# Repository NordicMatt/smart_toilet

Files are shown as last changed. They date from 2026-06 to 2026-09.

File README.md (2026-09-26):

# Smart Toilet — voice-triggered flush

> ✨ **Say "Abracadabra," and the toilet flushes.** No buttons, no app —
> just your voice and a little magic.

## The story

This started when the electronic capacitive-sensing toilets I have stopped working
correctly, and I felt the need to fix it. I rigged them up to flush from a button
press, monitored by an Arduino, and added a Hall effect sensor to read the motor
shaft position so it always stops at home.

I'd wanted to make it voice-activated for *years*. I tried with an nRF5340 and Edge
Impulse and could never get it working, so I put it away and lived with the button.

Then Nordic released the new **Edge AI Lab** and **Edge AI add-on**, and everything
changed. I built this ML model in about an hour. You can too — it's genuinely that
easy. And with the **Nordic MCP**, you can do nearly all of it without writing much
code. Give it a try!

I designed the enclosure using **Claude** and **Codex** together, iterating a few
times until everything was the way I liked it. It's the 3D-printed "magic chest" the
hardware lives in below.

Everything here is open source. The one exception is Nordic's AI, which is licensed
to run only on Nordic microcontrollers.

---

**Smart Toilet** is a voice-activated flush actuator for the **nRF54LM20 DK**, built
on the nRF Edge AI add-on. Saying the magic word **"Abracadabra"** drives a flush
motor through one rotation and stops it at the home position using a Hall sensor.

Wake-word detection runs fully on-device on the Axon AI accelerator — **no audio
ever leaves the board.** With the **nRF7002 EB II** Wi-Fi shield the device also
connects to **Memfault** over HTTPS for crash/metric monitoring, reports its flush
count as a Memfault metric, and receives firmware updates over the air via
**Memfault Release Management**. The application runs in **wake-word-only mode**.

- Board target: `nrf54lm20dk/nrf54lm20b/cpuapp` (secure, no TF-M)
- Wi-Fi shield: `nrf7002eb2` (on the P17 expansion connector)
- Application mode: `APP_MODE_WW_ONLY`
- Wake word: "Abracadabra" (`APP_WW_MODEL_ABRACADABRA`)

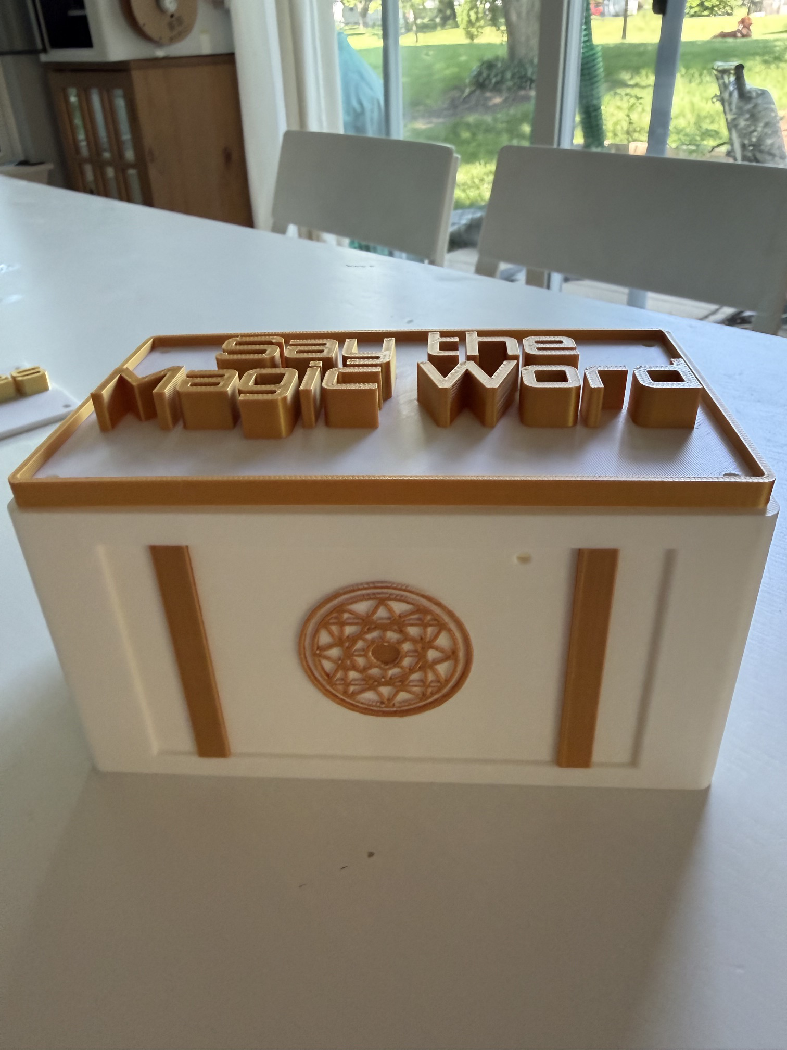
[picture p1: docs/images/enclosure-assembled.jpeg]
Assembled enclosure


The hardware lives in a 3D-printed "magic chest" enclosure (sources in
[`enclosure/`](enclosure/)) whose lid reads *Say the Magic Word*.

| Lid | Internals |
|-----|---|
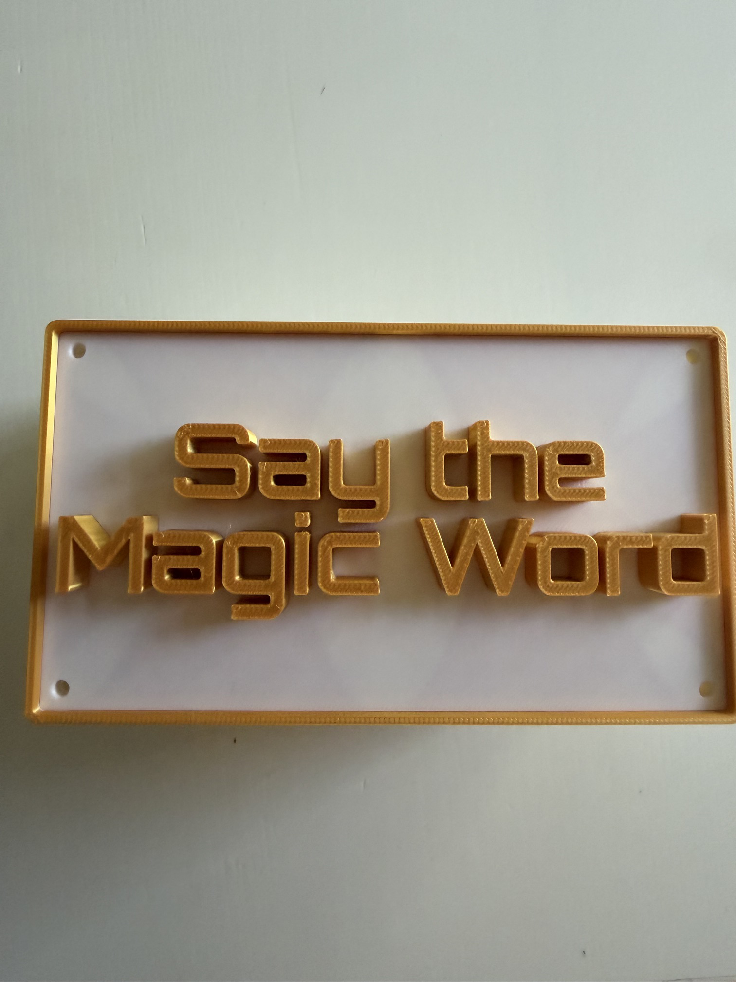
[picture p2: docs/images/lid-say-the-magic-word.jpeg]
Lid lettering
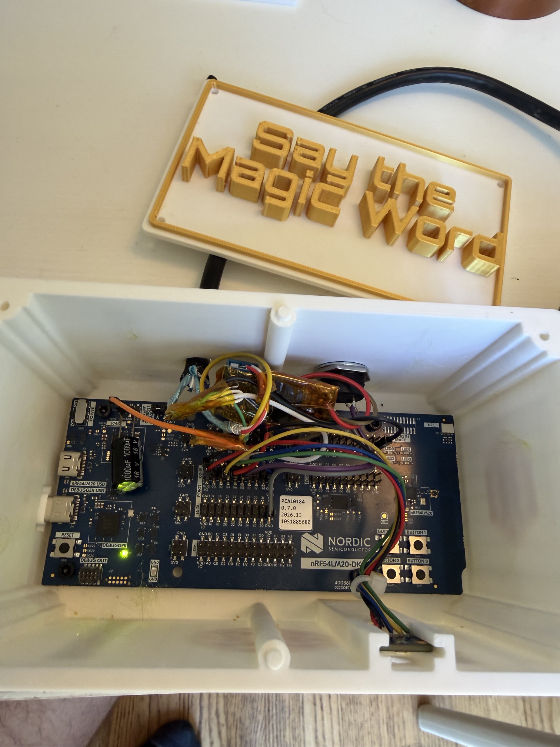
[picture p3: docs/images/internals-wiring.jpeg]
DK wired into the enclosure
|  |  |

## How it works

1. The PDM microphone (`pdm20`) captures single-channel 16 kHz audio (`src/dmic.c`).
2. Each audio block passes through the front-end cleanup chain (`src/audio_proc.c`):
   a fixed PDM hardware gain, a high-pass filter, then software AGC — see
   [Audio front-end](#audio-front-end) below.
3. The wake-word model (an nRF Edge AI Lab model, selected by the
   `APP_WW_MODEL` Kconfig choice) runs on the Axon accelerator (`src/ww/`). A
   detection requires the per-frame probability to exceed
   `CONFIG_WW_PROBABILITY_THRESHOLD` (0.60) for 7 of the last 20 ~30 ms frames,
   plus a ~1 s refractory period so one utterance fires exactly once.
4. On detection, `actuator_flush()` runs the motor and stops it when the Hall
   sensor sees the shaft magnet return home (`src/actuator.c`). LED0 blinks for
   one second and `Wakeword detected` is printed on the control UART (VCOM0).
5. In parallel, `src/cloud.c` brings up Wi-Fi and connects to **Memfault over
   HTTPS** to upload diagnostics, publish the flush count, and check for firmware
   updates. Audio capture only starts **after** the network is up, so the TLS
   bring-up never competes with the wake-word inference for CPU and DMIC buffers.

**Why "Abracadabra":** wake words with more syllables and plosive consonants
survive far-field room reverb far better. The original 2-syllable "Shazaam"
managed only ~50% detection at the deployment distance; "Abracadabra"
(5 syllables, plosive-rich with alternating open vowels) reaches ~95–100%.

## Audio front-end

Each 10 ms audio block is cleaned up before it reaches the model. The chain is,
in order:

1. **PDM hardware gain** — `CONFIG_APP_PDM_GAIN_DB` (default **+20 dB**) applied
   in the PDM peripheral via `nrf_pdm_gain_set()` in `src/dmic.c` (the Zephyr
   DMIC API does not expose gain). Sized for far-field use; without it, speech at
   the deployment distance peaks around −25 dBFS.
2. **High-pass filter** — `CONFIG_APP_AUDIO_HPF`, a 2nd-order Butterworth
   high-pass at **120 Hz**. There is little speech energy below the cutoff, so it
   strips low-frequency rumble and handling noise at negligible cost to the model
   input.
3. **Automatic gain control (AGC)** — `CONFIG_APP_AGC` tracks the speech peak
   envelope and applies a smoothed software gain (±12 dB) that pulls speech
   toward `CONFIG_APP_AGC_TARGET_DBFS` (**−20 dBFS**), so detection is far less
   sensitive to how far the speaker is from the mic.

The AGC acts *after* the PDM hardware gain, so it cannot undo saturation that
already happened in the peripheral — keep `APP_PDM_GAIN_DB` low enough that close
or loud speech does not clip (the model returns ~0 probability on saturated
audio). See [Tuning the mic and wake word](#tuning-the-mic-and-wake-word).

## Hardware / pinout

The EB II mounts on the **P17** expansion connector and claims several pins, so the
toilet peripherals live on header **P2** (GPIO port P1):

| Signal | Pin | Notes |
|---|---|---|
| Motor drive | P1.06 | Active-high → logic-level MOSFET gate |
| Hall sensor | P1.12 | Active-low, internal pull-up; **power the sensor from 5 V** (DK headers P6–P10/P18 pin 1) |
| PDM mic CLK | P1.14 | Adafruit 3492 (ST MP34DT01-M) |
| PDM mic DAT | P1.15 | mic SEL→GND (left channel), VDD→IO rail |
| Wi-Fi | P17 | nRF7002 EB II — don't wire anything else here |

> **Keep all peripheral wires off the `P1` connector block** — that block carries
> GPIO port P0, including the console UART (`P0.06`/`P0.07`). A stray wire there
> makes the console go silent for any firmware.
>
> **Do not use P2.00–P2.05** as header GPIO: the board controller mux routes them
> to the onboard QSPI flash, so the header pins are dead by default.

### Wiring

```
 nRF54LM20 DK                         External circuit
 ------------                         ----------------
 P1.06  ───────────────► gate         logic-level MOSFET
 GND    ───────────────► source       drain ─► motor(-) , motor(+) ─► motor supply +
                                       (flyback diode across the motor)

 5V0 (P6..P18 pin 1) ──► Hall VCC      Hall switch, magnet on the motor shaft
 GND ─────────────────► Hall GND
 P1.12 ◄──────────────── Hall OUT      idles ~3.6 V, pulls to 0 V when magnet present

 P1.14 ──► mic CLK   P1.15 ◄── mic DAT   Adafruit 3492 (SEL→GND, VDD→IO rail)

 P17 expansion connector ◄───────────► nRF7002 EB II (Wi-Fi)
```

Keep all grounds common (DK GND, motor-supply GND, Hall GND). The Hall idles at
~3.6 V, which is at the nRF GPIO input maximum — add a resistor divider if you
see flaky reads.

### Actuator tuning

In `src/actuator.c`:

- `HALL_BLANKING_MS` (250) ignores the Hall sensor right after start — the magnet
  rests on the sensor at home, so without blanking, start-up jitter would end the
  flush immediately.
- `MOTOR_SAFETY_MS` (1000) forces the motor off if the magnet is never sensed
  (jam, misaligned magnet, faulty sensor) so it cannot burn out. One rotation is
  ≈ 700 ms.

## Wi-Fi

Connectivity comes from the **nRF7002 EB II** on P17. `src/cloud.c` uses `conn_mgr`
to bring the interface up and connect, then obtains time over NTP (needed for TLS
certificate validity checks) before connecting to Memfault. The app connects with
Wi-Fi credentials stored in NVS (Zephyr
`wifi_credentials`); provision them with the `wifi cred add -s "<SSID>" -k <keymgmt>
-p "<PASSWORD>"` shell command (on a build with `CONFIG_SHELL`) or compiled-in
static `CONFIG_WIFI_CREDENTIALS_STATIC_SSID`/`_PASSWORD`. Credentials persist across
reboots and a `west flash` without `--erase`.

## Memfault (diagnostics + FOTA)

The device talks only to **Memfault**, directly over **HTTPS** — there is no
nRF Cloud connection. `CONFIG_MEMFAULT_HTTP_ENABLE=y` authenticates with the
Memfault project key (passed at build time — see [Build & flash](#build--flash));
the device serial is the hardware ID. Memfault's TLS root certificates are
provisioned at boot (`CONFIG_MEMFAULT_NCS_PROVISION_CERTIFICATES`), so there are
no application-managed certificates.

What `src/cloud.c` does:

- **Diagnostics** — `CONFIG_MEMFAULT=y` captures coredumps (RAM-backed, surviving
  the warm reset that `CONFIG_RESET_ON_FATAL_ERROR=y` performs after a fault),
  reboot reasons, and metrics, plus a GNU build ID for symbolication. The cloud
  thread drains the Memfault packetizer and POSTs chunks to Memfault over HTTPS.
- **Flush count** — the lifetime count is persisted in NVS (`toilet/flush_count`)
  and published as the Memfault metric **`flush_count`** in each heartbeat, so it
  survives reboots and shows up in the device timeline. (There is no nRF Cloud
  shadow channel, so the old remote-flush command was dropped.)
- **FOTA** — firmware updates are delivered by **Memfault Release Management**.
  `memfault_zephyr_fota_start()` checks the device's cohort for a newer release
  and downloads the signed image over HTTPS into the external-flash MCUboot
  secondary slot; MCUboot swaps it on reboot and the app confirms it once it is
  back online (so it survives a power-cycle). See
  [docs/fota-test.md](docs/fota-test.md) for the full push-an-update flow.

One-time cloud setup: upload the ELF (`build/app/zephyr/zephyr.elf`) under
**Software → Symbol Files** so coredumps symbolicate (matched by the GNU build ID
logged at boot, `mflt: GNU Build ID: …`).

## Tuning the mic and wake word

With `CONFIG_APP_AUDIO_STATS=y` (on by default in `prj.conf`), the log — on **VCOM0**
with the shield (it disables VCOM1) — prints one line of each per second:

```
audio: peak -4.2 dBFS, rms -21.7 dBFS, clipped 0/16000
ww: peak prob 0.62 (bar 0.60), peak votes 4/7
```

Say the wake word from the normal use position and read the lines for that second:

- **`clipped` > 0 or peak pinned at 0.0 dBFS** → the mic is distorting; lower
  `CONFIG_APP_PDM_GAIN_DB` (0.5 dB hardware steps, range −20..+20).
- **Speech peaks below about −20 dBFS** → too quiet for the model; raise
  `CONFIG_APP_PDM_GAIN_DB`.
- **`peak prob` never crosses the bar** even with healthy levels → lower
  `CONFIG_WW_PROBABILITY_THRESHOLD` (in 1/1000).
- **`peak prob` crosses but `peak votes` stays short of the target** → the hits
  are too spread out; lower `CONFIG_WW_COUNT_THRESHOLD` or raise
  `CONFIG_WW_HISTORY_SIZE`.

Set `CONFIG_APP_AUDIO_STATS=n` for the deployed build. (The `CONFIG_APP_AUDIO_SNAP`
audio-recording feature is currently **non-functional in any build variant** —
its raw-UART backend was removed from `control_output.c` when that file was
rewritten to share VCOM0 with printk logging, and never reimplemented. The
Kconfig option is gated off until it's restored; see `app/Kconfig`.)

## Build & flash

Built against an NCS **v3.4.0** tree with the nRF Edge AI add-on passed as extra
Zephyr modules, the Wi-Fi shield, the cloud config overlay, and three secrets kept
out of the repo entirely (`~/.memfault_project_key`, `~/.wifi_ssid`,
`~/.wifi_password` — none of these are committed; cloud.conf only enables
`CONFIG_WIFI_CREDENTIALS_STATIC`, it never contains the actual SSID/password):

```sh
KEY=$(tr -d '\n' < ~/.memfault_project_key)
SSID=$(tr -d '\n' < ~/.wifi_ssid)
WIFI_PW=$(tr -d '\n' < ~/.wifi_password)
nrfutil sdk-manager toolchain launch --ncs-version v3.4.0 --chdir ~/ncs/v3.4.0 -- \
  west build -p always -b nrf54lm20dk/nrf54lm20b/cpuapp -d build app -- \
    -DSHIELD=nrf7002eb2 \
    -DEXTRA_CONF_FILE=cloud.conf \
    -DZEPHYR_EXTRA_MODULES=<addon>/edge-ai \
    -DCONFIG_MEMFAULT_NCS_PROJECT_KEY=\"$KEY\" \
    -DCONFIG_WIFI_CREDENTIALS_STATIC_SSID=\"$SSID\" \
    -DCONFIG_WIFI_CREDENTIALS_STATIC_PASSWORD=\"$WIFI_PW\"
```

Flash and reset (pass `--dev-id <JLINK_SN>` when more than one DK is attached; add
`--erase` when the partition layout changed, e.g. switching from a TF-M /ns image):

```sh
nrfutil sdk-manager toolchain launch --ncs-version v3.4.0 -- \
  west flash -d build --dev-id <JLINK_SN>
```

Footprint: FLASH ~45 %, RAM ~85 % of the nRF54LM20B.

### Fleet (deployed) build

The images on the toilets are the low-power variant, not the plain recipe above:
same command with `-d build_lp` and `-DEXTRA_CONF_FILE="cloud.conf;lowpower.conf"`
(6 h heartbeat, 12 h DRAIN window). Three things that have to line up, learned the
hard way on 2026-09-26 when building 2.3.8 on a machine that had only ever built 2.2.1:

- **Install the toolchain under the SDK's own version name**:
  `nrfutil sdk-manager toolchain install --ncs-version v3.4.0`, then launch with
  `--ncs-version v3.4.0 --chdir ~/ncs/v3.4.0`. Only names printed by
  `nrfutil sdk-manager toolchain list` work; a missing one fails with "Selected
  toolchain was not found". (v3.4.0 and v3.4.0-rc2 resolve to the same bundle,
  fbf7391cab, so an rc2-only install builds identical binaries, but keep the
  release name so the recipe matches the tree.)
- **The Edge AI add-on checkout must be at v2.3.0** (`git -C <addon>/edge-ai checkout
  v2.3.0`). Firmware 2.3.0+ registers the class-streak observability metric; an
  older add-on makes Kconfig abort on the undefined
  `NRF_EDGEAI_OBSV_METRIC_CLASS_STREAK_DIST` symbols.
- **The OTA payload is `app.signed.bin` inside `build_lp/dfu_application.zip`**
  (`unzip -o build_lp/dfu_application.zip app.signed.bin -d build_lp/`), byte-identical
  to `build_lp/app/zephyr/zephyr.signed.bin`. Check the version string in the binary,
  not the build log: `strings build_lp/app.signed.bin | grep Booting`.

Fleet-build footprint (2.3.8): FLASH 40 %, RAM 97.5 %. There is ~13 KB of RAM left;
see PLAN_low_power.md for why the heartbeat interval is coupled to that number.

### Output

With the EB II shield the application console (logs **and** any shell) is on **VCOM0**
(UART30); VCOM1 is disabled by the shield. Use the lower-numbered `ttyACM`/COM port.
`tools/uart_monitor.py` is a small pyserial reader/monitor. Representative lines:

```
cloud: Network ready; uploading to Memfault over HTTPS
main: Network connected; starting audio capture
Waiting for wakeword
Wakeword detected
cloud: Flush #1 recorded
```

## Notes / lessons learned

- **Keep mic/motor/Hall wires on the `P2` connector block, not `P1`.** The console
  UART (`P0.06`/`P0.07`) is on the `P1` block; a stray wire there makes the console
  go silent for any firmware.
- **P2.00–P2.05 are not usable as header GPIO** — the board controller routes them
  to the onboard QSPI flash; disabling the flash in devicetree does not reconnect
  the header pin.
- **Power the Hall sensor from 5 V.** On the 3 V rail it never asserted. The output
  is **active-low** — verify polarity with a meter.
- The flush stop uses a **blanking window**, not a leave-then-return state machine,
  because the magnet rests on the sensor at home.
- **Pick a long, plosive-rich wake word.** Short fricative-led words lose the
  high-frequency energy room reverb destroys. See the `APP_WW_MODEL` choice.
- **Single, bounded heap:** the app uses newlib (required by Edge AI) while the Wi-Fi
  supplicant force-selects `COMMON_LIBC_MALLOC`; both default to a heap at `_end` and
  collide. `CONFIG_COMMON_LIBC_MALLOC_ARENA_SIZE` is fixed so the common heap is a
  static buffer and newlib's `_sbrk` heap gets the region above `_end`.
- **The onboard J-Link can wedge** (VCOM silent / `west flash` J-Link DLL error /
  `Unknown part number 0x33`). Retry `west flash` 1–3×; replug USB if it stays stuck.
- With two DKs attached, always pass `--dev-id <JLINK_SN>` to `west flash`.

## License

This project is licensed under the Nordic 5-Clause License
(`LicenseRef-Nordic-5-Clause`) — see [LICENSE](LICENSE). It is intended for use
with Nordic Semiconductor integrated circuits.

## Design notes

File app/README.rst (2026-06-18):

.. _smart_toilet_app:

Smart Toilet — voice-triggered flush
####################################

.. contents::
   :local:
   :depth: 2

The **Smart Toilet** application is a voice-activated flush actuator for the nRF54LM20 DK.
It detects the magic word **"Abracadabra"** from a digital microphone stream using |EAILib| and Axon-based inference, and on detection drives a flush motor through one rotation.

All inference runs on-device on the Axon AI accelerator; no audio leaves the board.

Application overview
********************

The application samples single-channel 16 kHz audio from a PDM microphone, cleans it up with a front-end audio chain, and feeds it to an nRF Edge AI wake-word model.
By default it runs in **wake-word-only mode** (``APP_MODE_WW_ONLY``): it listens continuously for the single phrase "Abracadabra" and never switches to a keyword-spotting stage.

When the wake word is detected, the application:

* blinks **LED0** for one second,
* prints ``Wakeword detected`` on the control UART (VCOM0),
* runs the flush motor through one rotation and stops it at the home position using a Hall sensor.

Model output is post-processed with a predictions-history window. The detection parameters are the per-frame probability threshold, the predictions-history length, and the number of predictions above the threshold required within that window. A short refractory period ensures a single utterance fires exactly once.

.. note::

   The application also supports wakeword-gated keyword spotting and keyword-spotting-only modes through the ``APP_MODE`` Kconfig choice, and bundles a keyword-spotting model (Go, Stop, Up, Down, Yes, No, On, Off, Right, Left). These are not used by the deployed Smart Toilet, which is wake-word-only.

Wake word
=========

The active wake word is selected by the ``APP_WW_MODEL`` Kconfig choice:

* ``APP_WW_MODEL_ABRACADABRA`` (default) — "Abracadabra", a 5-syllable, plosive-rich phrase from nRF Edge AI Lab. ~95–100% detection at far-field in live testing.
* ``APP_WW_MODEL_OKAY_NORDIC`` — "Okay Nordic", the add-on's bundled 4-syllable model, kept as a known-good reference (~85–90% far-field).

Longer, plosive-rich words survive far-field room reverb much better. A short fricative-led word loses exactly the high-frequency energy that reverb destroys, so it collapses at distance.

Audio front-end
===============

Each audio block is processed in :file:`src/audio_proc.c` before detection, in this order:

#. **PDM hardware gain** — ``APP_PDM_GAIN_DB`` (default +20 dB) applied in the PDM peripheral, sized for far-field use.
#. **High-pass filter** — ``APP_AUDIO_HPF``, a 2nd-order Butterworth high-pass at 120 Hz that strips rumble and handling noise below the speech band.
#. **Automatic gain control (AGC)** — ``APP_AGC`` tracks the speech peak envelope and applies a smoothed software gain toward ``APP_AGC_TARGET_DBFS`` (-20 dBFS), making detection less sensitive to speaker distance. It is gated below -38 dBFS so it rides utterance peaks instead of amplifying room noise.

The AGC acts after the PDM hardware gain and cannot undo saturation in the peripheral itself, so keep ``APP_PDM_GAIN_DB`` low enough that close or loud speech does not clip.

Replacing the model
===================

You can replace the wake-word model using the `Text to Wake Word Detection <Nordic Edge AI Lab Wake Word Detection_>`_ feature of the `Nordic Edge AI Lab`_ or one of the `ready-to-use models <Nordic Edge AI Lab ready-to-use models_>`_:

#. Add the generated files under a new directory in :file:`src/ww/models/`.
#. Add a matching option to the ``APP_WW_MODEL`` Kconfig choice and point :c:func:`ww_init` at the new model instance.
#. Adjust the ``WW_*`` Kconfig options to tune detection post-processing for your model.

Requirements
************

The application supports the following development kit:

.. table-from-sample-yaml::

It also requires a PDM digital microphone connected to the pins specified in the :file:`boards/nrf54lm20dk_nrf54lm20b_cpuapp.overlay` file, and the flush motor and Hall sensor described under `Pin mapping`_. Audio is expected on the left channel.

Pin mapping
===========

The application was tested with an `Adafruit PDM MEMS Microphone`_ module, powered from the 1.8V ``VDD:IO`` supply.

.. list-table::
   :header-rows: 1

   * - Signal
     - nRF54LM20 DK pin
     - Notes
   * - Motor drive
     - ``P1.06``
     - Active-high, drives a logic-level MOSFET gate
   * - Hall sensor
     - ``P1.07``
     - Active-low with internal pull-up; power the sensor from 5V
   * - Microphone ``CLK``
     - ``P1.04``
     - Adafruit PDM MEMS microphone
   * - Microphone ``DAT``
     - ``P1.05``
     - Microphone ``SEL`` → ``GND`` selects the left channel; ``VDD`` → ``VDD:IO`` (1.8V)

.. note::

   Do not use ``P2.00``–``P2.05`` as header GPIO on this DK: the board controller mux routes them to the onboard QSPI flash, so the header pins are inactive by default. Use ``P1``/``P3`` GPIO instead.

To use other microphones, adapt the PDM configuration parameters in the :file:`src/dmic.c` file.

User interface
**************

LED0:
   Blinks for one second when the wake word is detected (wake-word-only mode).

LED1:
   Blinks for one second on each keyword spotted (keyword-spotting modes only).

Flush motor:
   Runs through one rotation on wake-word detection and stops at the home position via the Hall sensor.

UART30 (VCOM0):
   Prints runtime state messages:

   * ``Waiting for wakeword``
   * ``Wakeword detected``

UART (VCOM1):
   Zephyr log output, including actuator events and, when ``APP_AUDIO_STATS`` is enabled, per-second microphone level, AGC gain, and wake-word probability statistics for tuning.

Configuration
*************

|config|

Configuration options
=====================

|application_kconfig|

.. options-from-kconfig::
   :show-type:

Building and running
********************

.. |application path| replace:: :file:`app`

This application is built against the nRF Edge AI add-on. See the repository
``README.md`` for the full ``west build`` and ``west flash`` command lines.

Testing
=======

|test_application|

#. |connect_kit|
#. |connect_terminal_kit| The application uses both serial ports.
#. Open one terminal for the control output from UART30 (VCOM0) and one for the Zephyr log (VCOM1).
#. Say the magic word "Abracadabra" from the normal use position.
#. Observe **LED0** blink for one second and the flush motor run through one rotation.
#. Observe ``Wakeword detected`` on VCOM0.

Application output
==================

The application shows the following output from UART30 (VCOM0):

.. code-block:: console

   Waiting for wakeword
   Wakeword detected

Dependencies
************

This application uses the following |EAI| library:

* :ref:`nrf_edgeai_lib`

This application uses the following Zephyr libraries:

* `Logging`_
* Audio (DMIC)
* GPIO
* UART Driver

API documentation
*****************

.. doxygengroup:: ww_kws

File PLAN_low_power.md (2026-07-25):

# Low-Power Branch Plan

Goal: take the full-connectivity, full-power smart toilet (main branch, v2.0.18)
and find out how low we can push average current, ending with battery operation
on the nPM1300. Voice function stays always-on; connectivity becomes periodic.

## Architecture: duty-cycled connectivity

Replace the always-connected model with a connection window state machine:

- **OFFLINE** (default state): Wi-Fi interface down, nRF70 powered off. No
  association exists, which entirely sidesteps the Nest-mesh silent-drop
  class of problems (nothing to drop) and the link-flap heap pressure
  (no packets). Memfault data (heartbeats, metrics, any coredumps from
  reboots) buffers on-device.
- **DRAIN** (periodic, e.g. every N hours or M heartbeats): bring the
  interface up, connect, upload all buffered Memfault chunks, run one FOTA
  check, then disconnect and power the radio back down. Window closes on
  completion or on a hard timeout so a bad Wi-Fi day cannot pin the radio on.

Audio (PDM capture + AXON inference + flush actuation) runs continuously in
both states. The toilet always hears; it just phones home on a schedule.

## Work items

### Phase 1: connectivity duty cycle (biggest win, most rework)
1. Connection-window state machine in cloud.c: net_if_down/up + conn_mgr,
   nRF70 power off between windows (confirm the driver's power path when the
   interface is administratively down; check whether iface down alone gates
   the RPU or if we need pm_device on the nrf70 node).
2. Memfault buffering between windows: today chunks drain continuously.
   Size the event/chunk storage for the offline period (RAM first; consider
   flash-backed storage if windows get long). Lost-heartbeat behavior after
   watchdog reboots already noted on main; offline buffering makes storage
   sizing matter more.
3. Watchdog semantics rework: the cloud stall monitor and upload-success
   proofs assume continuous connectivity. They must arm only inside DRAIN
   windows. The audio watchdog is untouched.
4. Fleet alerting: the Memfault Device Offline alert (id 21563) fires at
   15 min silent. Raise its threshold above the duty-cycle period (or key it
   to greater than 2x the period) or every sleep window emails everyone.
5. FOTA within the window: check runs once per DRAIN. A pending update
   extends the window until the download/swap completes. Deploy-to-device
   latency becomes up to one period; that is the accepted tradeoff.

### Phase 2: local power reductions (from the axon_low_power sample + earlier findings)
6. CONFIG_PM_DEVICE + CONFIG_PM_DEVICE_RUNTIME, carefully: verify no
   interaction with continuous PDM capture; suspend UARTs and unused
   peripherals. One change at a time with measurements.
7. Quiet build variant: SERIAL/CONSOLE/LOG/PRINTK off (sample's approach).
   Memfault remains the only diagnostics path; acceptable because that is
   how the fleet is debugged anyway. Keep a debug overlay that restores UART.
8. Energy-gated inference (VAD): skip NN passes while block energy sits at
   the room noise floor, with a hangover period and ww_reset() on resume
   (model is stateful). The audio_stats energy accumulator already computes
   what the gate needs. This cuts the AXON + CPU duty cycle during the many
   silent hours; the mic keeps capturing.
9. Audit thread priorities/periods for wakeup reduction (logging thread,
   timers) once measurements identify who wakes the CPU.

### Phase 3: measurement rig (before/throughout, not after)
10. Borrow the axon_low_power GPIO trace pattern: pins high during inference
    and during DRAIN windows, correlated on PPK2. Add a Kconfig'd overlay.
11. PPK2 profiling runbook for the whole board (DK + nRF7002 EB): baseline
    current on main vs low-power branch per phase. Record numbers in this
    file as they land.
12. New heartbeat metrics: time-in-DRAIN per heartbeat, buffered-chunk count,
    connect duration, plus the existing wifi_heap watermark.

### Phase 4: battery (nPM1300)
13. nPM1300 EK integration: devicetree + charger config (400 mA, 4.2 V
    termination per PROFILING.md) + nRF Fuel Gauge library, modeled on the
    NCS npm13xx_fuel_gauge sample.
14. Drop in the Lipo900 battery model .inc from the nPM PowerUP profiling
    run (see PROFILING.md; verify the profile finished and export the model).
15. Battery metrics to Memfault: state of charge, voltage, est. runtime.
    Low-battery behavior: extend duty cycle, then graceful shutdown.

## Open questions (decide before Phase 1 code)
- DRAIN period: hourly? every 6 h? Drives Memfault storage sizing, FOTA
  latency, and the offline-alert threshold. Proposal: start at 1 h.
- Coredump upload urgency: after a crash reboot, connect immediately rather
  than waiting out the period? Proposal: yes, one immediate window on boot.
- Remote knob: duty-cycle period as a Memfault-delivered setting or
  build-time constant? Build-time is simpler; no command channel exists.
- Keep WW-only mode as the low-power baseline (KWS stage stays off).

## Non-goals for this branch
- No changes to wake-word model or thresholds.
- Wi-Fi power-save (PS) stays off even in DRAIN windows; radio-off beats PS
  and avoids the whole silent-drop history.
- No hardware changes until Phase 4.

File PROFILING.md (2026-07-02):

# Battery Profiling Runbook — Li-ion, 3.7 V, 900 mAh

Generate a custom battery model for the nPM1300 fuel gauge using the
nPM PowerUP desktop app + nPM Fuel Gauge Board. The resulting `.inc` file
gets dropped into the smart_toilet firmware later for state-of-charge readings.

> Active profile: **`/home/matt/claude/Lipo900`** (capacity 900 mAh, 4.2/3.0 V,
> iChg 400 mA, 25 °C) — running as of 2026-06-26 (`csvReady: false`, no `.inc`
> yet). The old `smart_toilet/Palo/` folder (3000 mAh) is **stale — ignore it.**

## Battery parameters (decided)

| Field | Value | Note |
|---|---|---|
| Name | `Lipo900` | |
| Chemistry | Li-ion | 3.7 V nominal |
| Termination voltage | **4.2 V** | |
| Discharge cutoff | **3.0 V** | |
| Capacity | **900 mAh** | above the 400 mAh wizard minimum |
| Charge current | **400 mA** | ~0.44C (firmware charger matches) |
| Thermistor | **none / ignore** | 2-wire pack |
| Temperature | **25 °C only** | room-temp model; no chamber needed |

## Hardware required

- [ ] nPM1300 EK
- [ ] nPM Fuel Gauge Board (REQUIRED for a custom model — EK alone can't)
- [ ] PALO DY01 battery
- [ ] USB-C power supply, 1.5 A (charges the PMIC)
- [ ] USB-C cable to computer (nPM Controller)
- [ ] A PC that will NOT sleep/hibernate/auto-restart for ~2–3 days (use flight mode)

## Time expectation

Large cell, current-limited profiling. Charge ~7–8 h, discharge ~5–6 h, run
over multiple cycles. Expect **well over 48 h** for the single 25 °C model.
Run it over a long weekend.

## Step 1 — Attach Fuel Gauge Board to EK

1. [ ] Power off nPM Controller — disconnect USB from **J4**.
2. [ ] Plug Fuel Gauge Board's nPM EK header into the **EXT BOARD** socket.
       ⚠️ Align edge connectors **P1→P20** and **P2→P21** carefully.
3. [ ] Reconnect USB to **J4**. Green **LD4** = controller connected.

## Step 2 — Connect battery + power (no NTC)

1. [ ] Connect DY01 to **J1** (correct polarity).
2. [ ] Jumper **NTC (pin 2) ↔ 10 kΩ (pin 3)** on header **P3**.
       ⚠️ Charging will NOT start if this jumper is missing.
3. [ ] Connect USB-C 1.5 A supply to **J3** (USB PMIC) for charging.

(No nRF DK wiring needed for profiling — the Fuel Gauge Board does the discharge.)

## Step 3 — nPM PowerUP

1. [ ] nRF Connect for Desktop → open **nPM PowerUP**.
2. [ ] **Select Device → nPM1300 Evaluation Kit**.
3. [ ] Click **Profile Battery**.

## Step 4 — Enter wizard parameters

Use the table above. Thermistor = ignore/none, single temperature = 25 °C.
Pick an output folder for the model.

## Step 5 — Run

1. [ ] Start profiling. It charges fully, then discharge↔recharge cycles.
2. [ ] Do NOT change config mid-run (aborts). Keep PC awake. Flight mode on.
3. [ ] ⚠️ Heatsink gets HOT — let it cool before handling afterward.
4. [ ] On completion: model saved as both `.json` and `.inc` in your folder.

## After profiling

- The `.inc` file is the battery model for the firmware.
- Next: integrate nPM1300 into smart_toilet (devicetree + Kconfig + nRF Fuel
  Gauge library) and drop in this `.inc`. Modeled on the NCS
  `samples/pmic/native/npm13xx_fuel_gauge` sample.

## Optional: add temperature accuracy later

If the toilet sees temperature swings, profile at 5 °C and 45 °C separately
(needs a temperature chamber) and merge all three in the nPM PowerUP
**Profiles** tab into one multi-temp model.

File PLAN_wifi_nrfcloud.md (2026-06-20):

# Plan: Add nRF7002 EB II Wi-Fi + nRF Cloud (CoAP) to the Smart Toilet

> **⚠️ Superseded — historical planning record (2026-06-16).** The shipped design
> diverged from this plan: the build target is **`cpuapp`** (secure, no TF-M, not
> `/ns`), and the cloud side moved off nRF Cloud entirely to **pure Memfault over
> HTTPS** (diagnostics + FOTA), so the flush-count shadow and remote-flush command
> were replaced by a `flush_count` Memfault metric (no remote flush). The Wi-Fi
> bring-up and pin re-jumpering below still reflect the hardware. For the current
> architecture see [README.md](README.md) and [docs/fota-test.md](docs/fota-test.md).

**Decisions (2026-06-16):** Transport = **CoAP**; build target = **`nrf54lm20dk/nrf54lm20b/cpuapp/ns`** (TF-M);
cloud features = **flush-event device message + flush-count shadow + remote-flush command (polled)**.

Workspace: `/home/matt/ncs/edge_ai_addon` (already has shield `nrf7002eb2`, nRF70 driver,
`nrf_wifi` blobs, `nrf_cloud` CoAP lib, `nrf70-wifi` snippet, `/ns` board target). No manifest change needed.

## Hardware changes (must happen on the bench)
- **EB II mounts on P17** (expansion connector). It electrically claims: SPI P3.03/P3.02/P3.00/P3.01,
  BUCKEN **P1.04**, IRQ **P1.05**, IOVDDEN P1.13 (coex-only: GRANT P1.07, REQ P0.04, STATUS P0.03 — we will NOT use coex).
- **Mic conflict:** PDM CLK/DAT are on **P1.04/P1.05** → claimed by Wi-Fi. **Re-jumper the mic to two free GPIOs**
  (candidates: the freed UART20 pins, or other non-P17 header GPIOs). Update `pdm20_default_alt`. Verify with a meter.
- **Motor P1.06 / Hall P1.07:** keep, but jumper them on a header *other than P17* (the EB covers P17).
  Electrically free as long as coexistence stays disabled.
- **UART:** shield disables UART20 (VCOM1, the log port) and moves console to UART30 (VCOM0, our control-output port).
  Consolidate logging + control output on VCOM0. **Must disable VCOM1 in nRF Connect Board Configurator.**

## Phase 0 — Snapshot / git
- This repo is now git-tracked. Branch `wifi-nrfcloud`. Commit current working state first.

## Phase 1 — De-risk `/ns` + Axon (GATING SPIKE, before any Wi-Fi)
Axon is a hardware accelerator peripheral; under TF-M it must be assigned to the **non-secure** domain
(plus PDM20, GPIO1 for motor/Hall). Risk: TF-M default may not expose AXON/PDM IRQs to NS.
- Build the **existing** WW-only app for `nrf54lm20dk/nrf54lm20b/cpuapp/ns`.
- Resolve peripheral domain assignment (TF-M `tfm_manifest` / `nrf,peripheral` NS config / DT `*_ns` overlay).
- **Verify wake word still detects on `/ns`** before proceeding.
- Fallback if Axon can't go NS cleanly: revert to secure `cpuapp` and store cloud creds in NVS/settings
  (`TLS_CREDENTIALS_BACKEND_*` non-PSA). Update this plan if we fall back.

## Phase 2 — Wi-Fi link up (no cloud yet)
- `CMakeLists.txt`: `set(SHIELD nrf7002eb2)`; add `nrf70-wifi` snippet.
- `sysbuild.conf`: `SB_CONFIG_WIFI_NRF70=y`, `SB_CONFIG_WIFI_NRF70_SYSTEM_MODE=y`, `SB_CONFIG_BOOTLOADER_NONE=y`.
- `prj.conf`: nRF70 driver + WPA supplicant + native net stack + conn_mgr + L2_WIFI_CONNECTIVITY +
  WIFI_CREDENTIALS + settings/NVS + nRF Security/mbedTLS-DTLS + stacks/heaps
  (base on `nrf_cloud_multi_service/overlay_nrf700x_wifi_coap_no_lte.conf`).
- Wi-Fi credentials: static (`WIFI_CREDENTIALS_STATIC_SSID/PASSWORD`) for first bring-up,
  then move to wifi_cred shell / stored creds.
- Milestone: device associates to AP + gets DHCP IP (conn_mgr L4 connected event).

## Phase 3 — nRF Cloud over CoAP
- Kconfig: `NRF_CLOUD_COAP=y`, `NRF_CLOUD_MQTT=n`, `NRF_CLOUD_CLIENT_ID_SRC_*`,
  `COAP_CLIENT_*`, `DATE_TIME_NTP=y` (no modem time source), `NRF_CLOUD_ALERT`.
- Credentials/onboarding (host PC, separate from build):
  `pip install nrf-cloud-utils`; `device_credentials_installer.py --coap ...` then `nrf_cloud_onboard.py`.
  Creds land in TF-M Protected Storage (`/ns`).
- App: after L4-up → `nrf_cloud_coap_init()` → `nrf_cloud_coap_connect()`.

## Phase 4 — Application integration (the toilet logic)
- New `src/cloud.c/.h`: connection state machine on a workqueue/thread; conn_mgr event handlers.
- **Flush event:** from `actuator.c` flush-complete, post an nRF Cloud **device message** (e.g. `{"flush": {...}}`).
- **Flush counter:** increment a persisted counter (NVS), report to **device shadow** via `nrf_cloud_coap_shadow_*`.
- **Remote flush:** periodic `nrf_cloud_coap_shadow_get(delta=true)`; on a `flush:true` desired delta,
  call `actuator_flush()` and clear the delta. (CoAP is client-driven → poll, e.g. every N s.)
- Keep wake-word → flush path intact; cloud is additive and must never block the audio loop.

## Phase 5 — Verify
- Flash, watch VCOM0: Wi-Fi connect, CoAP connect, message on flush, shadow update in nRF Cloud portal,
  remote flush from portal triggers the motor. Confirm wake-word latency unaffected.

## Open items to confirm during implementation
- Exact two GPIOs for the relocated mic (meter-verify, avoid P2.00–P2.05 QSPI mux).
- Whether flash budget on nRF54LM20B fits Wi-Fi+WPA+mbedTLS+nrf_cloud without MCUboot (sample drops MCUboot for Wi-Fi).
- TF-M partition sizing (Protected Storage for creds).

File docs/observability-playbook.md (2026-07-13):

# Observability Playbook — Finding Fleet Problems Quickly

How the smart-toilet fleet (nRF54LM20 + nRF7002, NCS v3.4.0, Memfault via nRF
Cloud) is instrumented, how to triage an incident in minutes, and the lessons
that were paid for in debugging hours. Distilled from the v1.8.6 → v2.0.6
campaign (June–July 2026): five distinct Wi-Fi/crash root causes, one 14-hour
fleet-wide TLS outage, one FOTA crash loop, and a toddler-induced power event —
all diagnosed remotely except the ones that were physically a plug.

---

## 1. The observability stack (what's on the devices and why)

Layered so that every failure mode leaves evidence, and the evidence arrives
*with* the failure:

| Layer | What it captures | Where configured |
|---|---|---|
| **Reboot reasons** | Every reset with cause + raw `RESETREAS` register | Memfault core (free) |
| **Heartbeat metrics** (10 min) | Audio health (`audio_peak_dbfs`, noise floor, clipping), wake-word quality (`ww_prob_max/mean_pct`, `ww_inferences`, `ww_detections`), usage (`flush_count`, `button_press_count`), network (`wifi_disconnect_count`, `wifi_reconnect_count`), jam detection | `config/memfault_metrics_heartbeat_config.def` + `audio_telemetry.c` |
| **Coredumps** | All-thread backtraces (16 KB RAM-backed, 512 B/thread stacks) on every watchdog/fault | `prj.conf` (`MEMFAULT_RAM_BACKED_COREDUMP_SIZE`) |
| **Logs-in-coredumps** (v2.0.6) | Last ~2 KB of device log lines attached to every coredump — the story leading up to the crash | `CONFIG_MEMFAULT_LOGGING_ENABLE` + 2 KB ring |
| **ML observability CDR** (daily) | Wake-word probability histogram for model-drift monitoring | `CONFIG_NRF_EDGEAI_OBSV*` |
| **Watchdog ladder** | Guarantees every hang becomes a *diagnosed reboot*, not a dead unit | see §3 |
| **Server-side alert** | Device Offline email after 15 min of silence | Memfault alert (API-created) |

The design goal: **a device that fails should explain itself**. When a watchdog
fires, the coredump arrives with the reason, the wedged thread's backtrace, all
other threads, the metrics context, and (since v2.0.6) the log lines that
preceded it.

## 2. Triage: failure signatures → root cause in minutes

The first three API calls for any incident: `device_search` (who's alive, what
version), `device_listReboots` (what happened, when), `issues_list` (is it a
known signature). Then match against this table:

| Signature | Meaning | Go look at |
|---|---|---|
| `Software Watchdog at stall_monitor_expiry` + coredump | Cloud/upload stall ≥ 15–20 min (network outage, TLS failure) | `wifi_reconnect_count` burst in timeseries = outage window; logs in coredump for the TLS/DNS errors |
| `Task Watchdog` (audio) + coredump | Audio pipeline wedged ≥ 60 s (mic dead, model erroring) | Coredump logs will contain the repeating `DMIC read error` / inference error |
| `Hardware Watchdog` **during normal running** | Total lockup — kernel/sysclock dead. If recurring: suspect **memory corruption / ABI mismatch** (library built for a different SDK) | Version history: what library/SDK combination changed? |
| `Hardware Watchdog` **once, at an update** | FIXED in v2.0.11 (WDT budget 120 s → 10 min clears the MCUboot swap against external SPI-NOR). On ≥2.0.11, every HW-watchdog reboot is a real lockup. Historical entries ≤2.0.10 at version boundaries were this artifact | If seen on ≥2.0.11: treat as total lockup |
| `Stack Overflow at <fn>` | A thread's stack is too small for a (new) code path | The named function + coredump `SP` tells you *which* thread's stack Kconfig to bump |
| `Unspecified` / API shows `reason=0, mcu_reason_register=null` | **COLD reset — RAM wiped. This is POWER, not firmware.** Warm resets (all software causes) preserve the reboot-reason RAM | The plug. The USB supply. The child. |
| Offline, **no reboot event**, last heartbeats perfectly healthy | Power loss or total network cut. The device cannot report why it's gone | Physically check LED first; if lit, it self-recovers when network returns |
| `ww_inferences=0` while uptime climbs and uploads flow | Audio pipeline dead but loop alive (pre-v2.0.5 blind spot; now watchdogged) | v2.0.5+ turns this into a Task Watchdog with diagnostic coredump |
| `wifi_disconnect_count` stuck at 0 while the link is clearly dead | Silent half-open drop — radio asleep missed the deauth (power-save). Fixed by `CONFIG_NRF_WIFI_LOW_POWER=n` | Should not recur; if it does, PS got re-enabled |
| Whole fleet dark simultaneously, all versions | **Environment changed, not firmware** — server migration, cert/policy change, router. Rolling back versions will find "all broken" | Test the endpoint from a workstation on the same LAN (§4) |

**Zephyr errno decoder ring** (cost us hours): `errno 113` on Zephyr =
`ECONNABORTED` (TLS handshake aborted) — **not** Linux's `EHOSTUNREACH`. A "TLS
handshake error" log line means TCP already worked; routing/DNS theories are
wrong by construction.

## 3. The watchdog ladder (and its two design rules)

Escalating recovery, lightest first — every tier produces evidence:

| Tier | Trigger | Action |
|---|---|---|
| 0 | No upload 2 min while "connected" | Force Wi-Fi re-associate (no reboot) + `wifi_reconnect_count++` |
| 1 | Audio pipeline no progress 60 s | `MEMFAULT_TASK_WATCHDOG()` → coredump + reboot |
| 2 | Cloud thread no progress 15 min / no upload 20 min | `MEMFAULT_SOFTWARE_WATCHDOG()` → coredump + reboot |
| 3 | Wi-Fi down 10 min after having connected | Reason-marked warm reboot |
| 4 | **Hardware WDT** (nRF54 `wdt31` via `task_wdt`), 120 s | Hard reset even if the kernel is dead |

**Rule 1 — feed on work completed, never on loop-iteration-reached.** The v1.8.6
audio watchdog was fed at the top of the loop; a permanently failing
`dmic_read()` spun through its error path petting the watchdog forever — 45 min
deaf with healthy heartbeats. v2.0.5 feeds only after a mic block is read *and*
accepted by the model. Error paths must not feed.

**Rule 2 — software watchdogs all die together.** Every k_timer-based watchdog
depends on the kernel clock; a hard lockup kills them all silently. The
hardware WDT is not optional — it's the only tier that fires when everything
else is dead. It caught every v1.9.x lockup and contained a regression that
would otherwise have required nightly manual power cycles.

## 4. Debugging techniques that cracked the hard ones

- **`app/debug_net.conf` overlay** — DNS/DHCP/socket debug + mbedTLS handshake
  internals. Gotcha: you need all three of `CONFIG_MBEDTLS_DEBUG=y` (Zephyr
  glue), `CONFIG_MBEDTLS_LOG_LEVEL_DBG=y`, **and** `CONFIG_MBEDTLS_DEBUG_LEVEL=3`
  (nrf_security's prompted default of 0 silently wins otherwise). The payoff is
  decisive: it showed the server answering our ClientHello with `close_notify`
  — the whole TLS outage in one log line.
- **Workstation-as-control**: `openssl s_client` from the same LAN, constrained
  to the device's exact TLS parameters (`-tls1_2 -curves prime256v1 -cipher …
  -sigalgs …`, even `-noservername`), separates "server rejects everyone" from
  "server rejects *this device's* ClientHello".
- **The unrelated-host discriminator**: point the device's client at
  `www.google.com`. Google rejecting the ClientHello too (fatal alert 40)
  proved the ClientHello itself was defective — flipping the investigation from
  "who is blocking us" to "what are we sending". Found PSK-only ciphersuites in
  one step.
- **Raw reboot API beats the pretty UI**: `GET .../devices/<serial>/reboots`
  exposes `mcu_reason_register`. `reason=0` + `register=null` = RAM wiped =
  cold/power reset. This is the definitive power-vs-software discriminator.
- **Verify the binary, not the build log**: `strings zephyr.signed.bin | grep
  memfault.com` caught a "successful" build still carrying old endpoint
  hostnames. Build scripts should end with a self-verification block grepping
  `.config` and the binary for the change just made.
- **Upload symbols for *every* image that touches hardware** — including bench
  builds — or coredumps read "Unknown Location".

## 5. Release & deploy workflow

1. Bump `app/VERSION` **and** `CONFIG_MCUBOOT_IMGTOOL_SIGN_VERSION` (they must
   match; Memfault compares reported vs release version to offer OTA).
2. Pristine build with **`CCACHE_DISABLE=1`** (see lesson below), self-verify
   `.config` + binary.
3. `upload-mcu-symbols` (org token) → `upload-ota-payload` → `deploy-release`
   per cohort (**manager** email+token auth).
4. Watch pickup (~5–10 min: 60 s FOTA check → ~780 KB download → MCUboot swap →
   boot → report). Expect one benign HW-watchdog blip at the swap.
5. **Tag + push only when the version is actually on hardware.** Every flashed
   or OTA'd version gets a git tag — the reboot history is only interpretable
   against exact sources.

**Emergency stop for a bad OTA** (from the FOTA crash-loop incident): offering
*any* release to devices whose download path is broken restarts the loop, so —
`GET /deployments` → `DELETE /deployments/{id}` (manager auth; the org token
gets 403; the release-archive PATCH does not do the job). `deploy-release` of
the old version fails with "already active" when Memfault has auto-reverted —
that error is *good news*. When the download path itself is the bug, cohort
deploys must happen **after** each unit is bench-flashed, never before.

## 6. Lessons learned (the expensive ones)

**Platform & build**
- **Matched versions or memory corruption**: running a prebuilt add-on
  (edge-ai 2.2.0, built for NCS 3.4.0) on a different SDK (3.3.1) produced
  random total lockups — no crash pattern, just a dead kernel every few hours.
  If lockups correlate with a library update, check the ABI pairing first.
- **NCS 3.4.0 / mbedTLS 4.x makes crypto opt-in**: nothing you don't
  `PSA_WANT_*` exists. A Wi-Fi-personal build gets no ECDHE unless the app asks
  (`PSA_WANT_ALG_ECDH`, `ECC_SECP_R1_256`, `RSA_PKCS1V15_SIGN`,
  `ECC_KEY_PAIR_GENERATE/EXPORT`) — without them the TLS client offers
  PSK-only ciphersuites and every public server rejects it. Each missing want
  fails exactly one handshake step further: debug iteratively.
- **The same migration resizes stacks**: PSA-dispatched TLS (esp. SHA-384 PRF)
  needs more stack than legacy mbedTLS. Any thread that does TLS needs a
  re-audit — the `downloader` thread's 4352 B (fine on 3.3.1) overflowed
  fleet-wide on the first 3.4.0 OTA. 8 KB now.
- **ccache does not track `__has_include`**: after *adding* a header that an
  existing `#if __has_include(...)` probes for, cached objects keep the old
  branch — even `-p always` pristine builds. `CCACHE_DISABLE=1` or clear the
  cache.
- **Kconfig hygiene in 3.4.0**: warnings are hard errors; promptless/derived
  symbols (`NRF_SECURITY`, `PSA_WANT_KEY_TYPE_ECC_KEY_PAIR_BASIC`) must not be
  assigned in `.conf` files.

**Networking**
- The NCS Memfault port defaults to **deprecated** hosts
  (`chunks-nrf.memfault.com`); the documented current ones are
  `chunks.memfault.com` / `device.memfault.com` — overridden in
  `config/memfault_platform_config.h`.
- `DNS_RESOLVER_MAX_SERVERS=1`: a single static DNS server *evicts* the
  router's DHCP-provided resolver. Prefer the local resolver + TTL cache.
- Wi-Fi power save on a mesh network = silent half-open drops (radio sleeps
  through the deauth; `wifi_disconnect_count` stays 0). `CONFIG_NRF_WIFI_LOW_POWER=n`
  turned drops into *noticed* disconnects that conn_mgr auto-heals.
- All cloud calls must be time-bounded and are: HTTP poll 5 s, TLS connect
  10 s, DNS 30 s, TCP retransmit ~100 s. A 20-min "stall" is therefore
  *repeated fast failures during a real outage* (routers do overnight
  maintenance), not a hung call — the correct response is visibility
  (`wifi_reconnect_count`), not more timeouts.

**Observability itself**
- **Logs are only as good as their signal density**: a 1 Hz stats log wraps a
  2 KB ring in ~20 s, evicting the error lines the coredump exists to carry.
  Audit what's in the ring before shipping log capture ("do we have logs worth
  grabbing?" is the right question).
- **Per-interval event counters beat lifetime totals** for dashboard metrics
  (`heartbeat_add(1)` per event; keep lifetime totals in NVS if the device
  needs them).
- ISR-context events (button GPIO) stage through an atomic + semaphore; only
  thread context may touch Memfault metric APIs.
- Server-side CDR retention is 1/device/day — collect on that cadence, not
  faster.
- **Physical failures masquerade as software**: a wonky USB plug produced
  "Unspecified" resets and offline gaps that consumed hours as firmware
  theories. Cold-reset signature (§2) + "check the plug first" is the rule.
  Fleet postmortem: since v2.0.1, software outages: 0; power-connector
  outages: 3.

## 7. Incident checklist

```
1. date -u                                    # server clocks may skew from local
2. device_search                              # who's alive, what version
3. device_listReboots (both units)            # what + when; match §2 table
4. issues_list                                # known signature? trace_count growing?
5. If reboot has coredump  → trace_get: faulting thread, backtrace, attached logs
6. If no reboot event      → timeseries: last heartbeats healthy?
     abrupt-stop + no Wi-Fi events = power → check the plug/LED before any theory
7. If network-ish          → wifi_reconnect_count / wifi_disconnect_count timeseries;
     openssl from workstation on the same LAN as control
8. Fix → version bump → pristine CCACHE_DISABLE build → verify .config+binary
   → symbols → payload → deploy → watch pickup → tag + push
```

---

*Every version that ever ran on hardware is a git tag (`v1.8.6` … `v2.0.6`).
The full debugging narrative behind each is in the tagged commit messages —
they are the long-form changelog of this document.*

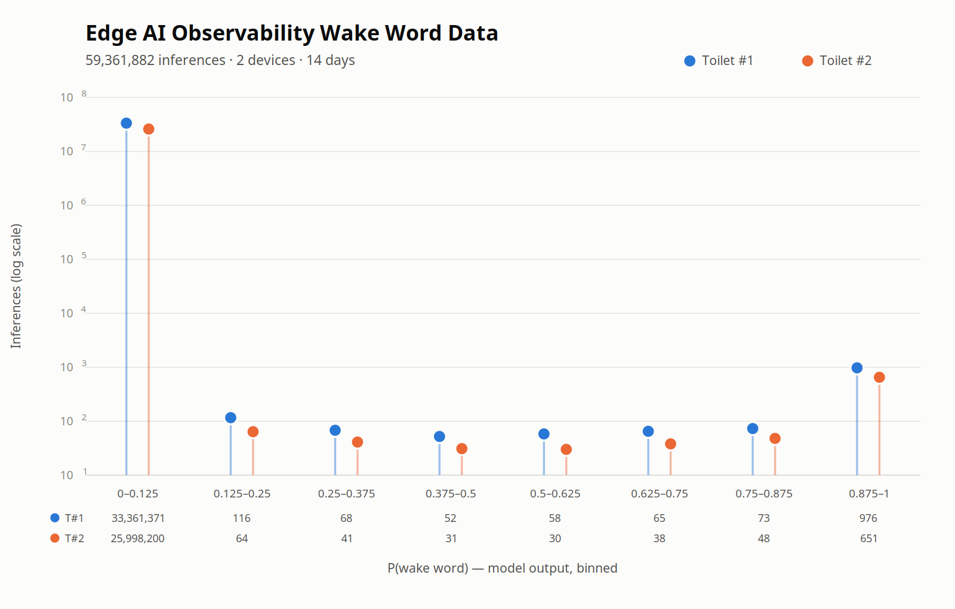
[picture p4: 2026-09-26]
docs/images/ww-confidence-distribution.png

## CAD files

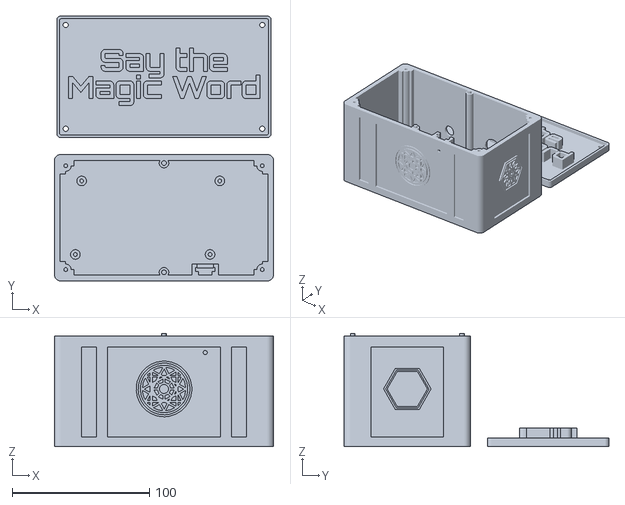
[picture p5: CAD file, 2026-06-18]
enclosure/enclosure.stl
159.6 x 192.8 x 82.5

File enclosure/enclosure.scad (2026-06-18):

/*
  Parametric enclosure for nRF54LM20DK project box.

  Default view renders base and lid separated for printing/inspection.
  Use:
    base();
    lid();
    assembled();
*/

$fn = 64;

use <magic_symbols.scad>   // Symbols traced from the Freepik abstract-symbol pack.

// ---------------------------------------------------------------------------
// Key dimensions
// ---------------------------------------------------------------------------

pcb_length = 145;
pcb_width = 63.5;
pcb_height = 10;

pcb_clearance  = 3;         // Internal clearance at each end (short walls).
side_clearance = 10;        // Internal clearance each long side — extra room for corner boss columns.
standoff_height = 6;        // PCB bottom height above enclosure floor — 6 mm gives M3 thread engagement.
height_above_pcb = 62;      // Free internal height above PCB top for 50.8 mm nRF7002 EB + ~8.5 mm header + margin.

wall_thickness = 2.5;
floor_thickness = 2.5;
lid_thickness = 3.5;        // Thicker top gives room for blind locating-pin pockets.
corner_radius = 3;

standoff_radius = 3.5;
screw_hole_radius = 1.4;    // M3 self-tap pilot (2.8 mm) — enlarged so screws drive in.

lip_depth = 1.5;            // Downward lid lip/rabbet engagement depth.
lip_thickness = 1.5;
fit_clearance = 0.25;       // Small FDM-friendly clearance for lid fit.

// USB-C opening on the left end wall, centered on the actual connector.
// Jack edges observed on the print: top edge at Z = 13.5 (old slot top), left edge
// at Y = -3 (old slot's +Y / left wall). Jack ~9 x 3.2 mm, so its center is offset
// inward by half its size from those edges.
usbc_center_y = -3 - 9/2;   // = -7.5  (left edge -3, minus half the 9 mm width)
usbc_center_z = 13.5 - 3.2/2; // = 11.9  (top edge 13.5, minus half the 3.2 mm height)
usbc_slot_w   = 15;         // Y opening — clears a USB-C cable connector with margin.
usbc_slot_h   = 8.5;        // Z opening.

// Interior front microphone breakout holder.
mic_board_w = 14;           // Mic breakout PCB width (X). VERIFY against actual board.
mic_board_slot_t = 3.0;     // Slot thickness (Y) — roomy fit so the board slides easily and wires have space.
mic_grip = 2.5;             // How much each side rail overlaps the board edge (X, per side).
mic_slot_depth = 18;        // How far down from the tower top the board slides.
mic_relief_t = 2.5;         // Relief pocket depth (Y) between front wall and board center, so the mic housing floats with an air gap.
mic_audio_hole_r = 1.5;     // Front audio hole radius (3 mm diameter).
mic_tower_wall = 2.5;       // Tower wall thickness.
mic_capsule_z_offset = 6;   // Audio hole height above slot bottom; adjust per actual mic capsule layout.
mic_tower_x = 30;           // Clears center locating column, corner bosses, and nearby PCB standoff/front PCB edge.
mic_wire_cut_w = 12;        // Wire exit slot width through the holder's back wall, open at the top so wires drop in.

// Corner bosses and lid screws.
boss_radius     = 4;
boss_hole_r     = 1.4;      // M3 self-tap pilot (2.8 mm) — enlarged so screws drive in.
boss_hole_depth = 12;
lid_screw_r     = 1.9;      // M3 clearance through lid (3.8 mm) — generous so the screw drops through.
gusset_width    = boss_radius * 3;  // Span of rectangular rib along each wall.

// Lid locating posts — chunky columns fused to the inside of the long walls, each
// with a pin on top that drops into a blind hole in the lid. They sit well inboard
// of the edge so the lid has material all the way around each hole (keeps the lid
// bottom flat — the holes are shallow blind pockets, not through-holes).
loc_col_r          = 3.5;   // Locating column radius.
loc_col_inset      = 2.0;   // Column center distance inboard from the inner wall face.
loc_pin_r          = 1.75;  // Pin radius (3.5 mm pin) — printable and sturdy.
loc_pin_h          = 2.0;   // Pin height above the wall rim.
loc_pin_hole_r     = 2.0;   // Lid hole radius = pin radius + clearance.
loc_pin_hole_depth = 2.5;   // Blind depth into the lid (leaves ~1 mm top skin).

label_line_1 = "Say the";
label_line_2 = "Magic Word";
label_font  = "Orbitron:style=Bold";
label_size  = 16;
label_line_pitch = 20;
label_height = 10;          // How far letters stand proud of the top surface.

// Magic-themed lid decorations (raised, like the lettering but lower).
deco_height       = 3;      // How far decorations stand proud of the top surface.
deco_border_inset = 0;      // Border frame flush with the lid edge, clear of the screw heads.
deco_border_width = 2;      // Border frame line width.

// Chest-style trim: bands wrapping the box, corner caps, and vertical straps.
strap_relief  = 1.8;        // How far bands/straps stand proud of the walls.
band_h        = 7;          // Bottom band height (stops just under the USB-C slot).
top_band_h    = 8;          // Top band height, flush with the rim.
strap_w       = 8;          // Vertical strap width.
strap_x       = 45;         // Vertical strap positions on front/back walls (+/-).
corner_cap_w  = 18;         // Corner cap leg length along each wall.

// Wall symbols (traced from the symbol pack, see magic_symbols.scad).
symbol_relief     = 1.2;    // How far symbols stand proud of the walls.
symbol_size_front = 40;     // Front medallion size.
symbol_size_back  = 36;
symbol_size_end   = 34;

// Through-holes in the upper part of the back wall (+Y side).
// (back_hole_z is set below, after base_height is defined.)
back_holes = [                    // Each entry is [x, diameter] along the back wall.
    [  25, 17.5 ],      // Switch mount.
    [ -25, 10.0 ],      // Wire pass-through.
];

part_gap = 14;              // Spacing between base and lid in default view.

// ---------------------------------------------------------------------------
// Derived dimensions
// ---------------------------------------------------------------------------

internal_length = pcb_length + 2 * pcb_clearance;
internal_width  = pcb_width  + 2 * side_clearance;
internal_height = standoff_height + pcb_height + height_above_pcb;

outer_length = internal_length + 2 * wall_thickness;
outer_width = internal_width + 2 * wall_thickness;
base_height = floor_thickness + internal_height;

back_hole_z = floor_thickness + standoff_height + pcb_height + 12;  // Hole centers 12 mm above the PCB top (z = 30.5), near the bottom like the original print.

lid_lip_length = internal_length - 2 * fit_clearance;
lid_lip_width = internal_width - 2 * fit_clearance;
lid_lip_outer_length = lid_lip_length;
lid_lip_outer_width = lid_lip_width;
lid_lip_inner_length = lid_lip_outer_length - 2 * lip_thickness;
lid_lip_inner_width = lid_lip_outer_width - 2 * lip_thickness;

outer_min_x = -outer_length / 2;
front_outer_y = -outer_width / 2;
front_inner_y = -internal_width / 2;

mic_tower_w = mic_board_w + 2 * mic_tower_wall;
mic_tower_depth = mic_relief_t + mic_board_slot_t + mic_tower_wall;
mic_board_channel_w = mic_board_w + 0.5;
mic_relief_w = mic_board_channel_w - 2 * mic_grip;
mic_slot_bottom_z = base_height - mic_slot_depth;
mic_slot_cut_h = mic_slot_depth + 0.4;
mic_slot_cut_z = mic_slot_bottom_z - 0.1 + mic_slot_cut_h / 2;
mic_tower_overlap = 0.05;
mic_slot_wall_bite = 0.1;   // Relief pocket bites slightly into the wall face so the pocket front is exactly the wall.
mic_audio_hole_z = floor_thickness + internal_height - mic_slot_depth + mic_capsule_z_offset;

// ---------------------------------------------------------------------------
// Utility geometry
// ---------------------------------------------------------------------------

module rounded_rect_2d(length, width, radius) {
    offset(r = radius)
        square([length - 2 * radius, width - 2 * radius], center = true);
}

module rounded_box(length, width, height, radius) {
    linear_extrude(height = height)
        rounded_rect_2d(length, width, radius);
}

// PCB hole positions from (0,0) at bottom-left corner of board,
// converted to model coords (centered): subtract pcb_length/2 and pcb_width/2.
pcb_holes = [
    [ 8.0   - pcb_length/2,  5.0   - pcb_width/2 ],
    [ 12.6  - pcb_length/2,  58.5  - pcb_width/2 ],
    [ 106.0 - pcb_length/2,  5.0   - pcb_width/2 ],
    [ 113.1 - pcb_length/2,  58.5  - pcb_width/2 ],
];

module standoff_positions() {
    for (hole = pcb_holes)
        translate([hole[0], hole[1], 0])
            children();
}

module standoff() {
    difference() {
        cylinder(h = standoff_height, r = standoff_radius);
        translate([0, 0, -0.1])
            cylinder(h = standoff_height + 0.2, r = screw_hole_radius);
    }
}

module usbc_slot() {
    // Cut through the left end wall, centered on the USB-C jack.
    // Cube extends slightly past the outer face to avoid coincident-face artifacts.
    translate([
        -(outer_length / 2) + wall_thickness / 2,
        usbc_center_y,
        usbc_center_z
    ])
        cube([wall_thickness + 2 * strap_relief + 0.4, usbc_slot_w, usbc_slot_h], center = true);
}
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

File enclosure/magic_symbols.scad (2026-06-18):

// Symbols traced from abstract-symbol-collection-with-outline (Freepik).
// Each module is a 2D shape normalized to fit a 1 x 1 box, centered.

module symbol_front() {
    polygon(points = [[-0.0208,0.5],[0.0571,0.4974],[0.1455,0.4792],[0.2442,0.4377],[0.3169,0.3883],[0.3896,0.3156],[0.4416,0.2377],[0.4779,0.1519],[0.4987,0.0455],[0.4987,-0.0455],[0.4805,-0.1416],[0.4416,-0.2377],[0.387,-0.3182],[0.3169,-0.3883],[0.2182,-0.4506],[0.1039,-0.4896],[0.0182,-0.5],[-0.0545,-0.4974],[-0.1532,-0.4766],[-0.2468,-0.4351],[-0.3221,-0.3831],[-0.3844,-0.3208],[-0.439,-0.2403],[-0.4779,-0.1468],[-0.4987,-0.0325],[-0.4961,0.061],[-0.4805,0.139],[-0.439,0.2403],[-0.3844,0.3208],[-0.3195,0.3857],[-0.2286,0.4455],[-0.1455,0.4792],[-0.0156,0.4766],[-0.1195,0.461],[-0.2156,0.4247],[-0.2961,0.3727],[-0.3584,0.313],[-0.4156,0.2325],[-0.4519,0.1494],[-0.4727,0.0558],[-0.4753,-0.0273],[-0.4649,-0.1026],[-0.4286,-0.2065],[-0.3714,-0.2974],[-0.3169,-0.3545],[-0.2597,-0.3987],[-0.1818,-0.4403],[-0.0831,-0.4688],[0.013,-0.4766],[0.0987,-0.4662],[0.2104,-0.4273],[0.3065,-0.3649],[0.3662,-0.3052],[0.413,-0.2377],[0.4571,-0.1364],[0.4753,-0.0403],[0.4753,0.0403],[0.4571,0.1364],[0.4208,0.2247],[0.3662,0.3052],[0.3039,0.3675],[0.2312,0.4169],[0.1481,0.4532],[0.0519,0.474],[-0.0208,0.4247],[0.0519,0.4221],[0.1273,0.4065],[0.2104,0.3701],[0.2649,0.3338],[0.3195,0.2818],[0.3714,0.2091],[0.4078,0.1234],[0.4234,0.0455],[0.4234,-0.0455],[0.4078,-0.1234],[0.374,-0.2039],[0.3532,-0.2403],[0.3481,-0.2403],[0.3169,-0.2844],[0.2416,-0.3519],[0.1688,-0.3909],[0.0961,-0.4143],[0.0182,-0.4247],[-0.0494,-0.4221],[-0.1247,-0.4065],[-0.2052,-0.3727],[-0.2701,-0.3286],[-0.3273,-0.2714],[-0.3714,-0.2065],[-0.4052,-0.1286],[-0.4234,-0.0325],[-0.4208,0.0558],[-0.4052,0.1286],[-0.3688,0.2117],[-0.3299,0.2688],[-0.2675,0.3312],[-0.2052,0.3727],[-0.1169,0.4091],[-0.0156,0.4013],[-0.0805,0.3935],[-0.1273,0.3805],[-0.1922,0.3519],[-0.2078,0.3364],[-0.0805,0.2688],[-0.0104,0.3987],[0.0182,0.3987],[0.0857,0.2714],[0.2104,0.339],[0.1558,0.3701],[0.1117,0.3857],[0.0468,0.3987],[0.0052,0.3753],[-0.0597,0.261],[-0.0338,0.2429],[0.0338,0.2429],[0.0649,0.261],[-0.2442,0.3156],[-0.3065,0.2584],[-0.3143,0.2429],[-0.2442,0.2429],[-0.2156,0.3156],[-0.2182,0.2429],[-0.0935,0.2429],[-0.0987,0.2532],[0.2208,0.3156],[0.1013,0.2532],[0.1013,0.2429],[0.2208,0.2429],[0.2468,0.3156],[0.2442,0.2429],[0.3169,0.2429],[0.2909,0.2766],[-0.3143,0.2195],[-0.2545,0.1026],[-0.2442,0.0948],[-0.2442,0.2195],[-0.2182,0.2195],[-0.2182,0.1104],[-0.213,0.1104],[-0.1455,0.1468],[-0.1091,0.2195],[-0.0805,0.2195],[-0.1065,0.1701],[-0.026,0.2117],[-0.0364,0.2195],[0.039,0.2195],[0.0286,0.2091],[0.1143,0.1649],[0.0883,0.2195],[0.1143,0.2195],[0.1532,0.1442],[0.2208,0.1078],[0.2208,0.2195],[0.2442,0.2195],[0.2442,0.0948],[0.2545,0.0922],[0.3221,0.2195],[-0.3377,0.2117],[-0.3688,0.1571],[-0.3844,0.113],[-0.4,0.0117],[-0.2701,0.0792],[0.3403,0.2039],[0.2753,0.0792],[0.4,0.0117],[0.387,0.1078],[0.3688,0.1597],[0.3506,0.1961],[-0.0078,0.1935],[-0.1169,0.1338],[-0.0727,0.0896],[-0.0442,0.1052],[-0.0078,0.113],[0.0156,0.1883],[0.0156,0.1104],[0.0442,0.1052],[0.0753,0.0844],[0.1247,0.1286],[0.1195,0.1364],[-0.1325,0.1182],[-0.1922,0.0091],[-0.1117,0.0091],[-0.1065,0.0403],[-0.0883,0.074],[0.1403,0.113],[0.0935,0.0688],[0.1091,0.0351],[0.1117,0.0117],[0.1974,0.0117],[0.1455,0.113],[-0.1688,0.1078],[-0.2182,0.0818],[-0.2182,0.0351],[-0.213,0.0273],[0.1818,0.1026],[0.1792,0.0974],[0.1922,0.0714],[0.2208,0.0273],[0.2208,0.0818],[-0.0104,0.0896],[-0.0468,0.0766],[-0.0701,0.0558],[-0.0883,0.0169],[-0.0883,-0.0143],[-0.0753,-0.0481],[-0.0571,-0.0688],[-0.0208,-0.087],[0.0078,-0.0896],[0.0519,-0.074],[0.0727,-0.0532],[0.0883,-0.0195],[0.0883,0.0195],[0.0753,0.0506],[0.0519,0.074],[0.0234,0.087],[-0.2623,0.0584],[-0.374,-0.0039],[-0.2597,-0.0636],[-0.2442,-0.0377],[-0.2442,0.0377],[-0.2519,0.0532],[0.2649,0.0584],[0.2442,0.0247],[0.2442,-0.0247],[0.2649,-0.061],[0.374,-0.0039],[0.1117,-0.0117],[0.1065,-0.0429],[0.0883,-0.0714],[0.1403,-0.1208],[0.1974,-0.0117],[-0.1896,-0.0143],[-0.1403,-0.1104],[-0.1273,-0.1234],[-0.0831,-0.0766],[-0.1039,-0.0455],[-0.1117,-0.0143],[-0.3974,-0.0169],[-0.3974,-0.0506],[-0.3844,-0.113],[-0.3688,-0.1571],[-0.3377,-0.2091],[-0.2727,-0.0844],[0.4,-0.0169],[0.2779,-0.0818],[0.3403,-0.2039],[0.3532,-0.1909],[0.3844,-0.1156],[-0.2104,-0.0273],[-0.2182,-0.0351],[-0.2182,-0.087],[-0.1662,-0.113],[0.2208,-0.0273],[0.213,-0.0325],[0.174,-0.1104],[0.2208,-0.087],[0.0727,-0.087],[0.0442,-0.1052],[0.013,-0.1104],[0.013,-0.1961],[0.1221,-0.139],[-0.0623,-0.0922],[-0.1143,-0.1442],[-0.0104,-0.1961],[-0.0104,-0.113],[-0.0442,-0.1052],[0.2519,-0.0948],[0.2442,-0.1],[0.2442,-0.2195],[0.3221,-0.2195],[0.2571,-0.0948],[-0.2468,-0.0974],[-0.2545,-0.1026],[-0.3143,-0.2195],[-0.2442,-0.2195],[-0.1636,-0.113],[-0.1662,-0.113],[-0.1662,-0.1156],[-0.1636,-0.1156],[0.2208,-0.113],[0.1506,-0.1494],[0.1143,-0.2195],[0.2208,-0.2195],[-0.2182,-0.1156],[-0.2182,-0.2195],[-0.1091,-0.2195],[-0.1455,-0.1519],[0.1065,-0.1727],[0.0338,-0.2117],[0.0286,-0.2195],[0.0883,-0.2195],[0.1117,-0.1753],[-0.1013,-0.1753],[-0.1039,-0.1753],[-0.1039,-0.1779],[-0.1013,-0.1779],[-0.1013,-0.1779],[-0.0805,-0.2195],[-0.026,-0.2195],[-0.3143,-0.2429],[-0.3039,-0.261],[-0.2442,-0.3156],[-0.2442,-0.2429],[-0.2182,-0.2429],[-0.2182,-0.3208],[-0.0909,-0.2532],[-0.0935,-0.2429],[-0.0234,-0.2429],[-0.0571,-0.2636],[0.0052,-0.3753],[0.0623,-0.2636],[0.0234,-0.2429],[0.1013,-0.2429],[0.0961,-0.2558],[0.1039,-0.261],[0.2208,-0.3208],[0.2208,-0.2429],[0.2442,-0.2429],[0.2468,-0.3156],[0.2883,-0.2792],[0.3169,-0.2429],[-0.0779,-0.274],[-0.2052,-0.3442],[-0.1195,-0.3831],[-0.0442,-0.3987],[-0.013,-0.3987],[0.0831,-0.2766],[0.0182,-0.3987],[0.0623,-0.3961],[0.1195,-0.3831],[0.2052,-0.3442],[0.1948,-0.3338]], paths = [[0,1,2,3,4,5,6,7,8,9,10,11,12,13,14,15,16,17,18,19,20,21,22,23,24,25,26,27,28,29,30,31],[32,33,34,35,36,37,38,39,40,41,42,43,44,45,46,47,48,49,50,51,52,53,54,55,56,57,58,59,60,61,62,63],[64,65,66,67,68,69,70,71,72,73,74,75,76,77,78,79,80,81,82,83,84,85,86,87,88,89,90,91,92,93,94,95,96,97],[98,99,100,101,102,103,104],[105,106,107,108,109,110],[111,112,113,114,115],[116,117,118,119],[120,121,122,123],[124,125,126,127],[128,129,130,131],[132,133,134,135],[136,137,138,139,140],[141,142,143,144],[145,146,147,148],[149,150,151,152],[153,154,155,156],[157,158,159,160,161],[162,163,164,165,166,167],[168,169,170,171,172],[173,174,175,176,177,178],[179,180,181,182,183],[184,185,186,187,188,189],[190,191,192,193],[194,195,196,197,198],[199,200,201,202,203,204,205,206,207,208,209,210,211,212,213,214],[215,216,217,218,219,220],[221,222,223,224,225],[226,227,228,229,230],[231,232,233,234,235,236],[237,238,239,240,241,242],[243,244,245,246,247],[248,249,250,251],[252,253,254,255],[256,257,258,259,260],[261,262,263,264,265],[266,267,268,269,270],[271,272,273,274],[275,276,277,278],[279,280,281,282],[283,284,285,286],[287,288,289,290,291],[292,293,294,295],[296,297,298],[299,300,301,302],[303,304,305,306],[307,308,309,310,311],[312,313,314,315,316],[317,318,319,320],[321,322,323,324,325],[326,327,328,329,330,331]]);
}
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

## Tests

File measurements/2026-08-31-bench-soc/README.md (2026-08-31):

# 2026-08-31 bench SoC captures — inference cost split

Rig: second nRF54LM20 DK (J-Link **1051814190**) + nRF7002 EB II, PPK2 in
**ampere-meter mode at P14** (VDD:nRF, 1.8 V), no microphone attached, no
motor/Hall. This DK does not enumerate on USB until PPK2 DUT power is on.
Firmware: `low-power` branch bench builds (300 s DRAIN period). Capture:
`tools/ppk2_capture.py --seconds 380 --voltage-mv 1800`, P1.13 marker not
wired (threshold split in post).

| Capture | Build | Floor (windows excluded) |
| --- | --- | --- |
| `soc_run1` | `2.2.1-bench` (full pipeline) | **0.648 mA** |
| `soc_noinfer` | `2.2.1-bench-noinfer` (`-DAPP_BENCH_NO_INFERENCE`: capture + DSP, `ww_process()` skipped, watchdog fed) | **0.285 mA** |

**Inference = 0.363 mA, 56 % of the SoC floor.** That is the measured
ceiling on what an audio-level (VAD) gate could save in a quiet room.
Details and interpretation in `docs/POWER_MEASUREMENT.md`.

Files:

- `soc_*_1ms.csv` — 1 ms downsample (`t_s, mean_uA, max_uA`), plot-friendly.
- `raw/soc_*.csv.gz` — full ~85 kS/s captures (~600 MB uncompressed each,
  `index,current_uA,digital`). Kept out of git; do not commit.

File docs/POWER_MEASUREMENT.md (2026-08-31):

# PPK2 current measurement (low-power branch)

Measured 2026-07-27 on a third nRF54LM20 DK + nRF7002 EB II running
`build_bench` (`app/bench_power.conf`, 300 s DRAIN period). Tool:
`tools/ppk2_capture.py`.

## Results

| Subsystem | State | Current |
| --- | --- | --- |
| **nRF7002** (5 V feed) | radio OFF, between windows | **0.087 mA** |
| **nRF7002** (5 V feed) | radio ON, 34 s window | **43.07 mA** (peak 305.8) |
| **nRF54LM20B** (VDD:nRF @ 1.8 V) | always-on audio + inference | **0.664 mA** |
| **nRF54LM20B** | during a window | ~2.9 mA (peak 20.5) |

**The RPU does power down.** 87 µA on the radio's 5 V feed is regulator
quiescent plus leakage; an nRF7002 left energised sits in the tens of mA.
The ratio between window and sleep is **1:495**. This closes the doubt
`PLAN_low_power.md` step 1 raised, with a measurement instead of an
inference. The `net_if_down ... Error: -120` (`-EALREADY`) logged at window
close is benign.

Projected radio average at the shipped 12 h period:

```
window:  43.07 mA x    34 s =  1464 mA·s
sleep:   0.087 mA x 43200 s =  3758 mA·s
                      total =  5223 mA·s / 43234 s = 0.121 mA
```

Sleep dominates at 12 h, so shortening the window buys almost nothing.
Further gains have to come from lowering the 87 µA floor.

### Budget and what is NOT in it

| Subsystem | Average | Source |
| --- | --- | --- |
| SoC | ~0.68 mA | measured |
| Radio @ 12 h duty | ~0.12 mA | measured |
| **Measured subtotal** | **~0.80 mA** | |
| PDM mic (MP34DT01-M) | ~0.65 mA | datasheet, NOT measured |
| Hall sensor, ungated | ~5 mA | typical part, NOT measured |
| Motor | unknown | NOT measured |

On a 900 mAh cell: SoC + radio ≈ 48 days; add the mic ≈ 26 days; add an
ungated Hall ≈ 6 days.

**`VDD:IO` is a buffered follower of `VDD:nRF`**, deliberately arranged so
shield I/O current is not drawn through the measured rail. The P14 figure is
therefore the **SoC only** — mic, external flash and the nRF7002's IOVDD are
in neither capture.

The 43 mA window figure includes the EB II's 5 V -> 3.6 V regulator, which
the battery design deletes, so the product number will be better.

## Setup as actually used

Both measurements are **ampere meter mode, in series**. The board keeps
supplying itself; the PPK2 only counts electrons. No sourcing, so no
brownout risk from the meter.

### Radio: cut SB31

The EB II's P10/P4 measurement headers are unreachable once the board is
seated, so the radio is measured upstream instead.

`SB31` ("cut to disconnect VBUS from 5V0:CONN") isolates the connector 5 V
rail that feeds the power headers P6-P10/P18, and hence the EB II. Cut it
and bridge the gap with the PPK2 in series: `VIN` to the VBUS side, `VOUT`
to the `5V0:CONN` side.

> **After cutting SB31 the radio only has power while the PPK2 has DUT
> power ON.** Between captures Wi-Fi is dead and every DRAIN window fails to
> connect. That is the rig, not a firmware regression. To run the DK
> normally, bridge the gap with a plain wire.

Non-destructive alternative, if starting over: interrupt **pin 1 only** of
the DK power header the EB II's P2 seats on (bend the pin, or use a riser)
and put the PPK2 in series there. Same measurement, nothing cut. The two
pinouts mate 1:1 — DK header pin 1 is `5V0 from PMIC`, EB II P2 pin 1 is
`VDD_VBAT`.

### SoC: P14, ampere mode

Remove the P14 jumper and connect the PPK2 **between pins 1 and 2**, which
is Nordic's documented ampere-meter setup for this DK. The onboard nPM1300
keeps supplying `VDD:nRF` at its native 1.8 V, so there is no risk of
running the SoC at the wrong voltage.

Source-meter mode at P14 also works (`--source-mode`, 1.7-3.6 V allowed),
but then the PPK2 *is* the supply and the DK must already be powered over
USB before output is enabled, or the onboard circuitry can be damaged.
Ampere mode avoids the ordering hazard entirely.

> With the P14 jumper out and the PPK2 in series, **the SoC only has power
> while DUT power is ON**, so the DK reboots when a capture starts.

## Where NOT to inject

`VBUS` feeds the **nPM1300 PMIC**, which generates every downstream rail.
Driving 5 V into `VBUS` or a `5V0` net while USB is also connected puts two
sources in parallel and current arrives via a path you are not measuring.

There is **no 5 V input that reaches the SoC**: the external supply header
is P14, rated **1.7-3.6 V**. The P6-P10/P18 headers are 5 V *outputs*.

Do not cut `SB18` for this. It separates `VSYS` from `P5V0`, and `VSYS` is
the PMIC's main system rail; it does not isolate the shield supply.

## Running a capture

```
tools/ppk2_capture.py --seconds 380                      # radio, 5 V rail
tools/ppk2_capture.py --seconds 380 --voltage-mv 1800    # SoC at P14
```

Always pass a `/dev/serial/by-id/...` path. **ttyACM numbers get reassigned**
when devices re-enumerate, and the PPK2 and the DK swap places.

380 s covers a full bench cycle (~34 s window + 300 s sleep).

### If the PPK2 returns garbage

Symptoms: `UnicodeDecodeError` reading modifiers, ~7 samples/s instead of
~80 000, absurd currents. The device was left mid-stream by a previous
session. `ppk2_capture.py` now quiesces automatically on connect; by hand it
is opcode `0x07` (AVERAGE_STOP) then drain. **`0x0d` is `REGULATOR_SET`, not
average-stop** — sending it by mistake misconfigures the device. `0x20` is a
full RESET, after which the device re-enumerates and the ttyACM number
changes.

### Other gotchas

- Close the serial terminal before taking real numbers; Nordic warn readings
  are noisy while the virtual serial port is open
- The window marker (`CONFIG_APP_POWER_MARKER`, P1.13) was **not wired** for
  these captures, so the split was done on current threshold. With 495x
  separation that is unambiguous, but wiring P1.13 to a PPK2 digital input
  gives exact edges
- LED1 pulses 20 ms every 5 s (`CONFIG_APP_LED_HEARTBEAT`), so expect a small
  periodic blip rather than a DC offset. A wake-word detection blinks it for
  a full second, so avoid talking near the unit mid-capture
- nRF Connect for Desktop polls serial ports for device discovery, which can
  disturb a scripted capture. Close it first

## SoC optimisation attempts (2026-07-27)

All measured at P14, ampere mode, 1.8 V, same 180-380 s method.

| Build | baseline | vs bench |
| --- | --- | --- |
| bench (serial + log + console) | 0.650 mA | — |
| `bench_quiet.conf` (SERIAL/CONSOLE off) | **0.622 mA** | **-28 uA** |
| `bench_pm.conf` (PM_DEVICE + RUNTIME) | 0.649 mA | ~0 |

**`PM_DEVICE_RUNTIME` saves nothing — do not adopt.** Functionally safe
(audio ran, DHCP landed, window completed, watchdog quiet), but the
peripherals that dominate are the ones actively in use. See
`app/bench_pm.conf`.

**`CONFIG_PM` is unavailable.** It depends on `HAS_PM`, which nRF54LM20 does
not advertise in NCS 3.4.0. Not a loss: the idle path is WFI, which is how
nRF54L reaches System ON IDLE (~3 uA).

**Serial-off was NOT promoted to the field build.** 28 uA is ~4% of the SoC
baseline and ~2% of the system budget, and the console has repeatedly been
needed for debugging. See `app/bench_quiet.conf`.

### DC/DC is already on — and your custom board must replicate it

The DK's board DTSI sets `&vregmain { status = "okay";
regulator-initial-mode = <NRF5X_REG_MODE_DCDC>; }`, confirmed as
`regulator-initial-mode = <0x1>` in the generated devicetree. Omitting this
is what left a DevZone custom board at **98 uA instead of ~1 uA** in System
OFF. It is the single highest-consequence line in a custom board's DTS.

### Where the SoC's power actually goes

Nordic quote System ON IDLE at ~3 uA; we measure ~620 uA. So **~99.5% of the
SoC draw is the work itself** — continuous PDM capture plus inference. No
configuration switch touches that. Reducing it means changing the algorithm
(e.g. a cheap voice-activity first stage gating the expensive model), not
the build config. For scale, the mic alone is ~650 uA per its datasheet,
comparable to the whole SoC, and sits outside this measurement on the
VDD:IO follower.

The two changes actually worth making are elsewhere: **gate the Hall
sensor** (~5 mA continuous) and **feed nRF7002 VBAT directly** (deletes the
EB II regulator and most of the 87 uA radio floor).

## SoC inference split (2026-08-31)

Measured on a second nRF54LM20 DK (J-Link **1051814190**) + EB II, PPK2 at
P14 ampere mode, no mic attached (the PDM peripheral clocks and DMAs
regardless; per-block model compute is data-independent, so the floor is
representative). Raw + downsampled traces in
`measurements/2026-08-31-bench-soc/`. Note: this DK does not enumerate on
USB until PPK2 DUT power is on.

| Build | Floor (windows excluded) |
| --- | --- |
| `2.2.1-bench`, full pipeline | **0.648 mA** |
| `2.2.1-bench-noinfer` (capture + DSP, no `ww_process()`) | **0.285 mA** |

**Inference is 0.363 mA — 56 % of the SoC floor.** This reproduces July's
baseline (0.648 vs 0.650) and finally splits it: the remaining 0.285 mA is
PDM capture + DMA + HPF/AGC/stats + idle. The raw trace is bimodal (median
0.305 mA under the full pipeline): the CPU already idles between per-block
compute bursts.

Consequence: an audio-level (VAD) gate that skips inference during silence
has a measured ceiling of **~0.36 mA** — by far the largest SoC lever, and
it confirms the July hypothesis quantitatively. A real gate keeps: cheap
`block_peak` (already computed by the AGC) with hysteresis + a few-hundred-
ms hangover, a pre-roll ring buffer to prime the model's ~1 s feature
history on gate-open, and a vote/refractory reset in `wakeword.c`. It only
pays off in quiet rooms — a bathroom fan can hold the gate open.

The experiment is repeatable with
`-DEXTRA_CFLAGS=-DAPP_BENCH_NO_INFERENCE` (guard in `main.c` ww_loop; it
feeds the liveness watchdog on mic progress so the 60 s coredump does not
fire; the image reports `2.2.1-bench-noinfer`).

System view with the gate (quiet room, 12 h duty): SoC 0.65 -> ~0.29 mA,
subtotal with radio ~0.77 -> ~0.41 mA (900 mAh: ~48 -> ~92 days). With the
mic attached (~0.65 mA, must stay powered — the VAD listens through it),
the mic becomes the single largest consumer: ~1.42 -> ~1.06 mA (~26 -> ~35
days). Past that, the lever is a different microphone: parts with hardware
acoustic-activity detection (e.g. TDK T5838-class, tens of µA until sound)
would gate the mic *and* the inference in hardware.

## Battery architecture (next phase)

The nPM1300 has two 200 mA step-down BUCKs, two 50 mA LDO / 100 mA load
switches, and `VSYS` (unregulated cell voltage). **It has no boost**, so on a
3.0-4.2 V cell there is no 5 V rail without an external converter.

Resolved by not needing 5 V anywhere:

| Load | Source | Rationale |
| --- | --- | --- |
| Motor | battery / `VSYS` direct | runs from cell voltage; via existing low-side MOSFET |
| nRF7002 VBAT | battery direct | VBAT range is 2.9-4.5 V, cell fits; deletes the EB II regulator |
| SoC, mic, flash, nRF7002 IOVDD | BUCK1 @ 1.8 V | ~30 mA worst case, inside 200 mA |
| Hall sensor | **LDO2 as load switch** | gate around `actuator_flush()` |

**The radio must not come off a BUCK.** Measured 306 mA peak at 5 V is
~360-430 mA at cell voltage, well past a 200 mA regulator.

**Gating the Hall sensor is the single biggest win.** At ~5 mA continuous it
exceeds every other load combined, and it only needs to be alive for the
seconds a flush takes.

Risks to design around:

- `VSYS` caps at 1 A from battery. Radio peak plus motor inrush can exceed
  it. Wiring the motor straight to the cell sidesteps the limit, at the cost
  of the fuel gauge not seeing that current
- A small LiPo's protection PCB can trip at 2-3 A. Check it against measured
  **inrush**, not running current
- Set the low-voltage cutoff above **2.9 V** for the nRF7002's VBAT floor,
  which is higher than the cell alone would need
- Motor inrush and radio TX share a rail today. Keep them on separate paths
  from `VSYS`, with bulk capacitance local to the motor

## Still unmeasured

1. **Motor inrush and stall current** — sizes the cell, the protection
   circuit, and whether `VSYS` is viable. The largest remaining unknown
2. **Hall sensor actual draw** — needs the part number
3. **Mic and external flash** — outside the P14 rail via the VDD:IO follower
4. Verify the Lipo900 battery model completed; it was `csvReady: false` as of
   2026-06-26 (see `PROFILING.md`)
5. **A real VAD gate's savings vs its detection cost** — the 0.36 mA figure
   above is the perfect-gate ceiling; the implemented gate needs an A/B on
   this rig for both power and wake-word reliability
6. **Whole-toilet battery draw** — planned once a toilet is rewired to the
   nPM1300 (profiling in progress 2026-08-31); the bench numbers here are
   the budget to check it against

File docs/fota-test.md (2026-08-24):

# FOTA test: pushing a new application image

End-to-end test of **Memfault FOTA over HTTPS** on the cloud unit
(`51AF63E40BF36313`, "Toilet #1"). Validates: a new image is downloaded directly
from Memfault over HTTPS, written to the MCUboot **secondary slot in external
MX25R64 flash**, swapped into the internal primary slot by MCUboot on reboot, and
**confirmed** so it survives a power-cycle.

Since the `spike/mcuboot-ext-flash-fota` merge into `main` (commit 9789cda),
`main` carries MCUboot + the external-flash secondary + Memfault FOTA, so this
works on a stock `main` build. (Earlier `main` had no bootloader and could not
do FOTA — that is the branch note this doc originally referred to.)

## Delivery path: Memfault Release Management (pure HTTPS)

The device talks only to Memfault. FOTA uses `CONFIG_MEMFAULT_ZEPHYR_FOTA` with
the NCS `fota_download` backend (`CONFIG_MEMFAULT_ZEPHYR_FOTA_BACKEND_NCS`,
Memfault SDK 1.40.0): `cloud.c` calls `memfault_zephyr_fota_start()`, which asks
Memfault whether a newer release is deployed to the device's cohort, and if so
downloads the signed image over HTTPS from the Memfault CDN
(`ota-cdn.memfault.com`) straight into the external-flash MCUboot secondary.
There is **no nRF Cloud connection** — a single TLS connection, so no
dual-connection memory pressure. Memfault's root CAs (incl. DigiCert for the CDN)
are provisioned at boot by `CONFIG_MEMFAULT_NCS_PROVISION_CERTIFICATES`.

**Version matching:** Memfault offers an update only when the cohort's active
release version differs from the device's reported version
(`CONFIG_MEMFAULT_NCS_FW_VERSION`, sourced from `app/VERSION`). The OTA-target
build must have a higher `app/VERSION` than what the device is running.

**Durability:** the bootloader runs a freshly-swapped image in *test* mode
(`CONFIG_BOOT_SWAP_USING_MOVE`) and reverts on the next reset unless it is
confirmed. `cloud.c` calls `boot_write_img_confirmed()` once the new image
reaches the network + Memfault, making the update permanent.

## How a swap is verified

Two ways, no UART required:

- **Memfault (remote):** the device reports a reboot with its software version on
  each boot. After the OTA the latest reboot shows the new version:

  ```sh
  ORG=$(cat ~/.memfault_org_slug); PROJ=$(cat ~/.memfault_project_slug)
  TOK=$(cat ~/.memfault_org_token)
  curl -sS -H "Authorization: Bearer $TOK" \
    "https://api.memfault.com/api/v0/organizations/$ORG/projects/$PROJ/devices/51AF63E40BF36313/reboots?per_page=4"
  ```

- **Serial (if attached):** `main.c` logs a boot marker every boot —
  `<inf> main: Smart Toilet firmware v1.2.0+0 starting`. A new version after the
  OTA means the swap worked. Keep `CONFIG_MCUBOOT_IMGTOOL_SIGN_VERSION` in
  `app/prj.conf` in sync with `app/VERSION`.

## Step 1 — Bootstrap the device (one-time, over the wire)

A device can only pull from Memfault once it is already running a build with the
Memfault FOTA client. The first such image must be flashed over J-Link. Build and
flash with a chip erase (partition layout differs from `main`); the Memfault
project key and Wi-Fi credentials are passed at build time from
`~/.memfault_project_key`, `~/.wifi_ssid`, and `~/.wifi_password` (none of these
are committed to the repo):

```sh
KEY=$(tr -d '\n' < ~/.memfault_project_key)
SSID=$(tr -d '\n' < ~/.wifi_ssid)
WIFI_PW=$(tr -d '\n' < ~/.wifi_password)
nrfutil sdk-manager toolchain launch --ncs-version v3.4.0 --chdir ~/ncs/v3.4.0 -- \
  west build -p always -b nrf54lm20dk/nrf54lm20b/cpuapp -d build app -- \
    -DSHIELD=nrf7002eb2 -DEXTRA_CONF_FILE=$PWD/app/cloud.conf \
    -DZEPHYR_EXTRA_MODULES=~/edge_ai_addon/edge-ai \
    -DCONFIG_MEMFAULT_NCS_PROJECT_KEY=\"$KEY\" \
    -DCONFIG_WIFI_CREDENTIALS_STATIC_SSID=\"$SSID\" \
    -DCONFIG_WIFI_CREDENTIALS_STATIC_PASSWORD=\"$WIFI_PW\"
DLL=~/.local/jlink/opt/SEGGER/JLink_V950/libjlinkarm.so
nrfutil device erase   --jlink-dll "$DLL" --serial-number 1051844848
nrfutil device program --jlink-dll "$DLL" --firmware build/merged.hex --serial-number 1051844848
nrfutil device reset   --jlink-dll "$DLL" --serial-number 1051844848
```

Confirm on VCOM0 (`/dev/ttyACM0`): `Smart Toilet firmware vX.Y.Z starting`, then
`Network ready; uploading to Memfault over HTTPS`.

## Step 2 — Build the OTA-target image (higher version)

Bump **both** version sources so the target is newer than the running image, then
build (NO flash — we want the signed binary only):

- `app/VERSION`: bump `VERSION_MINOR` (or another field)
- `app/prj.conf`: set `CONFIG_MCUBOOT_IMGTOOL_SIGN_VERSION` to match (e.g. `"1.2.0+0"`)

```sh
KEY=$(tr -d '\n' < ~/.memfault_project_key)
SSID=$(tr -d '\n' < ~/.wifi_ssid)
WIFI_PW=$(tr -d '\n' < ~/.wifi_password)
nrfutil sdk-manager toolchain launch --ncs-version v3.4.0 --chdir ~/ncs/v3.4.0 -- \
  west build -p always -b nrf54lm20dk/nrf54lm20b/cpuapp -d build app -- \
    -DSHIELD=nrf7002eb2 -DEXTRA_CONF_FILE=$PWD/app/cloud.conf \
    -DZEPHYR_EXTRA_MODULES=~/edge_ai_addon/edge-ai \
    -DCONFIG_MEMFAULT_NCS_PROJECT_KEY=\"$KEY\" \
    -DCONFIG_WIFI_CREDENTIALS_STATIC_SSID=\"$SSID\" \
    -DCONFIG_WIFI_CREDENTIALS_STATIC_PASSWORD=\"$WIFI_PW\"
```

The OTA payload is the **raw signed image** `app.signed.bin` (inside
`build/dfu_application.zip`). Memfault serves it as-is and `dfu_target` writes it
to the MCUboot secondary, so upload the `.bin`, **not** the zip:

```sh
unzip -o build/dfu_application.zip app.signed.bin -d build/
```

> Do NOT flash the target over the wire — the point is for it to arrive via FOTA.

## Step 3 — Upload + deploy to Memfault

Uses the Memfault CLI (`~/.memfault-venv/bin/memfault`). Credentials live in
`~/.memfault_*` (see the credentials memory). Upload accepts the org token;
`deploy-release` needs a Manager-role user key (`--email`/`--password`).

```sh
ORG=$(tr -d '\n' < ~/.memfault_org_slug); PROJ=$(tr -d '\n' < ~/.memfault_project_slug)
TOK=$(tr -d '\n' < ~/.memfault_org_token); MTOK=$(tr -d '\n' < ~/.memfault_manager_token)
VER="1.2.0+0"

~/.memfault-venv/bin/memfault --org-token "$TOK" --org "$ORG" --project "$PROJ" \
  upload-ota-payload --hardware-version nrf54lm20dk --software-type smart-toilet \
  --software-version "$VER" build/app.signed.bin

# REQUIRED: upload the ELF symbols for this build, or Memfault cannot decode the
# heartbeat metrics (audio_*, ww_*, flush_count, and the built-in metrics) — it
# maps metric indices to names using the symbol file. Without this, the device
# uploads heartbeats successfully but NO metrics appear in the timeline.
~/.memfault-venv/bin/memfault --org-token "$TOK" --org "$ORG" --project "$PROJ" \
  upload-mcu-symbols build/app/zephyr/zephyr.elf

~/.memfault-venv/bin/memfault --email matthew.heins@nordicsemi.no --password "$MTOK" \
  --org "$ORG" --project "$PROJ" \
  deploy-release --release-version "$VER" --cohort default
```

`--hardware-version nrf54lm20dk` and `--software-type smart-toilet` must match the
device's `CONFIG_MEMFAULT_NCS_HW_VERSION` / `CONFIG_MEMFAULT_NCS_FW_TYPE`, or the
device's OTA query won't match the release. **Symbols must be uploaded for every
build** (the `upload-mcu-symbols` step above) — it's also how coredumps
symbolicate.

## Step 4 — The device updates itself

The device polls Memfault every ~120 s (`FOTA_CHECK_S` in `cloud.c`); on the next
poll it sees the newer active release and downloads it. No action needed — just
keep the unit powered and on Wi-Fi. If serial is attached you'll see:

```
mflt: FOTA Update Available. Starting Download with URL: https://ota-cdn.memfault.com/...
downloader: Downloaded .../... bytes (NN%)
... reboot ...
main: Smart Toilet firmware v1.2.0+0 starting   <-- SWAP CONFIRMED
cloud: Running image confirmed (FOTA update made permanent)
```

End-to-end takes ~3.5–5 min (≈30 s to first poll + ~2–2.5 min download + swap).

## Step 5 — Verify

- **Device version flips:** the latest reboot in Memfault (or the boot banner)
  shows the new version.
- **Durability:** after the new image confirms, a power-cycle leaves it on the new
  version (it does **not** revert to the previous one). A swapped-but-unconfirmed
  image — e.g. one that never reaches the network — is reverted by MCUboot on the
  next reset, which is the intended safety net.

## Known caveats / what this exercises

- The **mixed-geometry swap** (internal-RRAM primary ↔ external-SPI 4 KB-sector
  secondary) — the main unknown from the spike; confirmed working.
- Download speed: keep `CONFIG_LOG_MODE_DEFERRED` (not immediate) — immediate
  logging formats a line per 1 KB block inline on the downloader thread and
  throttled the transfer to ~6 KB/s.
- `deploy-release` (activating a release for a cohort) requires the **Manager**
  role; the plain org token is upload/read-only (HTTP 403 otherwise).

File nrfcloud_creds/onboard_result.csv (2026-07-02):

bulkOpsRequestId | 01KWG71M3J986FWMWA9HTNEFKC
endpoint | ONBOARD_DEVICES
status | SUCCEEDED
requestedAt | 2026-07-02T01:28:12.146465737Z
completedAt | 2026-07-02T01:28:12.677649247Z
uploadedDataUrl | https://api.nrfcloud.com/v1/bulk-ops-assets/e0a6cccb-0a56-4f86-8c33-2fb59acb0a08/data-01KWG71M3J986FWMWA9HTNEFKC.csv
Error count | 0
Device ID | Result
51AF63E40BF36313 | OK
779FC2ACB9E4A24E | OK

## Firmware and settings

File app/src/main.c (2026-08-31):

/*
 * Copyright (c) 2026 Nordic Semiconductor ASA
 *
 * SPDX-License-Identifier: LicenseRef-Nordic-5-Clause
 */

#include <stddef.h>
#include <stdint.h>

#include <zephyr/audio/dmic.h>
#include <zephyr/device.h>
#include <zephyr/devicetree.h>
#include <zephyr/logging/log.h>

#include <app_version.h>

#include "actuator.h"
#include "audio_proc.h"
#include "audio_snap.h"
#include "audio_stats.h"
#include "audio_telemetry.h"
#include "audio_watchdog.h"
#include "cloud.h"
#include "control_output.h"
#include "dmic.h"
#include "kws/kws.h"
#include "leds.h"
#include "ww/wakeword.h"

LOG_MODULE_REGISTER(main);

#define DMIC_READ_TIMEOUT 100

/* Give Wi-Fi/Memfault a short head start before audio capture so their bring-up
 * doesn't fight the DMIC + edge-AI inference for CPU/RAM. Bounded: after this we
 * start audio regardless, so a Wi-Fi outage at boot never leaves the toilet
 * deaf. The cloud thread keeps trying to connect independently. */
#define AUDIO_START_NET_WAIT_S 30

static const struct device *const dmic_dev = DEVICE_DT_GET(DT_NODELABEL(dmic_dev));

/* Consecutive dmic_read() failures before restarting PDM capture in-place
 * (~1 s: each failed read blocks up to DMIC_READ_TIMEOUT=100 ms + 5 ms sleep).
 * A halted driver (ring overrun during Wi-Fi scan/reconnect bursts) never
 * recovers via reads alone; restarting here self-heals in ~100 ms where the
 * audio watchdog would otherwise reboot at 60 s. The watchdog stays as the
 * backstop if even restarts fail. */
#define DMIC_ERRS_BEFORE_RESTART 10

static int ww_loop(void)
{
	int err;
	void *audio_buffer;
	size_t audio_buffer_size;
	bool ww_detected;
	int dmic_errs = 0;

	ww_reset();

	print_control_output((struct control_message){CONTROL_MESSAGE_WAITING_WW});

	while (true) {
		/* NOTE: the liveness watchdog is fed on PIPELINE PROGRESS (mic block
		 * read AND accepted by the model), not merely on loop iteration.
		 * Feeding at the loop top masked the "loop alive, mic dead" wedge:
		 * a persistently failing dmic_read() spun through the error path,
		 * petting the watchdog forever while producing zero inferences
		 * (seen in the field: 45 min deaf with healthy heartbeats). The
		 * error paths below deliberately do NOT feed, so a persistent
		 * DMIC/inference failure trips the 60 s watchdog -> coredump (with
		 * the error visible) -> reboot -> recovered voice path. */
		err = dmic_read(dmic_dev, 0, &audio_buffer, &audio_buffer_size, DMIC_READ_TIMEOUT);
		if (err < 0) {
			/* A DMIC read error is transient (e.g. -EAGAIN: no block within
			 * the timeout, from a momentary CPU stall during Wi-Fi
			 * reconnection). Skip this block and keep listening — a dropped
			 * ~10 ms block is harmless. Crucially, do NOT return: that would
			 * exit the audio loop and leave the toilet deaf until reboot.
			 * No watchdog feed here: if this error persists, the mic is
			 * dead and the audio watchdog must fire.
			 */
			LOG_WRN("DMIC read error %d; skipping block", err);
			if (++dmic_errs >= DMIC_ERRS_BEFORE_RESTART) {
				dmic_errs = 0;
				(void)dmic_restart();
			}
			k_sleep(K_MSEC(5));
			continue;
		}
		dmic_errs = 0;

		audio_proc_run(audio_buffer, DMIC_SAMPLES_IN_BLOCK);
		audio_snap_feed(audio_buffer, DMIC_SAMPLES_IN_BLOCK);
		audio_stats_update(audio_buffer, DMIC_SAMPLES_IN_BLOCK);

#ifdef APP_BENCH_NO_INFERENCE
		/* Bench-only (EXTRA_CFLAGS=-DAPP_BENCH_NO_INFERENCE): capture and
		 * DSP run, inference is skipped, to measure what a perfect VAD
		 * gate could save. The watchdog must still be fed on mic progress
		 * or the 60 s liveness coredump fires. Never ship this. */
		audio_watchdog_feed();
		continue;
#endif

		err = ww_process(audio_buffer, DMIC_SAMPLES_IN_BLOCK, &ww_detected);
		if (err == -EBUSY) {
			/* More data is needed: the mic delivered audio and the model
			 * accepted it — the pipeline is healthy. */
			audio_watchdog_feed();
			continue;
		} else if (err < 0) {
			/* Edge-AI feed/inference error (e.g. -EPERM). Re-init the model
			 * state and keep listening — do NOT return, which would exit the
			 * audio loop and leave the toilet deaf until reboot (same rationale
			 * as the DMIC error above). dmic_read() at the loop top paces
			 * retries. No watchdog feed: persistent inference failure must
			 * trip the audio watchdog.
			 */
			LOG_WRN("Wakeword detection error %d; resetting model and continuing", err);
			ww_reset();
			continue;
		}

		/* Full inference completed. */
		audio_watchdog_feed();

		if (ww_detected) {
			audio_telemetry_detection();
			print_control_output((struct control_message){CONTROL_MESSAGE_WW_DETECTED});
			if (IS_ENABLED(CONFIG_APP_MODE_WW_ONLY)) {
				leds_blink_led0();
				actuator_flush();
			} else {
				return 0;
			}
		}
	}
}

static int kws_loop(void)
{
	int err;
	void *audio_buffer;
	size_t audio_buffer_size;
	struct kws_prediction prediction;
	int dmic_errs = 0;

	uint32_t spotting_timeout = k_uptime_get_32() + CONFIG_KWS_PERIOD_MS;

	kws_reset();

	print_control_output((struct control_message){.type = CONTROL_MESSAGE_WAITING_KW});

	while (IS_ENABLED(CONFIG_APP_MODE_KWS_ONLY) || spotting_timeout > k_uptime_get_32()) {
		/* Watchdog fed on pipeline progress, not loop iteration — see
		 * ww_loop() for rationale. */
		err = dmic_read(dmic_dev, 0, &audio_buffer, &audio_buffer_size, DMIC_READ_TIMEOUT);
		if (err < 0) {
			/* Transient (e.g. -EAGAIN). Skip the block and keep going rather
			 * than exiting the audio loop. See ww_loop() for rationale.
			 * No watchdog feed on the error path.
			 */
			LOG_WRN("DMIC read error %d; skipping block", err);
			if (++dmic_errs >= DMIC_ERRS_BEFORE_RESTART) {
				dmic_errs = 0;
				(void)dmic_restart();
			}
			k_sleep(K_MSEC(5));
			continue;
		}
		dmic_errs = 0;

		audio_proc_run(audio_buffer, DMIC_SAMPLES_IN_BLOCK);
		audio_snap_feed(audio_buffer, DMIC_SAMPLES_IN_BLOCK);
		audio_stats_update(audio_buffer, DMIC_SAMPLES_IN_BLOCK);

		err = kws_process(audio_buffer, DMIC_SAMPLES_IN_BLOCK, &prediction);
		if (err == -EBUSY) {
			/* More data is needed: pipeline healthy. */
			audio_watchdog_feed();
			continue;
		} else if (err) {
			/* Recover and keep going rather than exiting the audio loop.
			 * See ww_loop() for rationale.
			 */
			LOG_WRN("Keyword spotting error %d; resetting model and continuing", err);
			kws_reset();
			continue;
		}

		/* Full inference completed. */
		audio_watchdog_feed();

		if (prediction.valid) {
			leds_blink_led1();
			spotting_timeout = k_uptime_get_32() + CONFIG_KWS_PERIOD_MS;
			print_control_output(
				(struct control_message){.type = CONTROL_MESSAGE_KW_SPOTTED,
							 .kw_class = prediction.class,
							 .name = prediction.name});
		}
	}

	print_control_output((struct control_message){.type = CONTROL_MESSAGE_TIMEOUT_KWS});

	return 0;
}

/* The audio pipeline runs on its own thread so Wi-Fi control-plane work cannot
 * starve it. The wpa_supplicant thread runs at preemptive priority 0 by default
 * and its scan/reconnect bursts have repeatedly stalled the loop (then on the
 * priority-6 main thread) past the ~40 ms the 4-block PDM ring tolerates,
 * halting capture (see dmic_restart()). Priority 0 for audio -- with the
 * supplicant lowered to 3 in cloud.conf -- lets a due DMIC block preempt that
 * work, while the cooperative system workqueue (-1) and nRF70 IRQ workqueue
 * (-15) stay above audio, so Wi-Fi interrupt handling is unaffected. Despite
 * the high priority the loop cannot hog the CPU: it blocks in dmic_read() for
 * every 10 ms block and inference is a few ms every third block.
 *
 * Started via k_thread_start() from main() after init and the network head
 * start; SYS_FOREVER_MS keeps it parked until then.
 */
static void audio_thread_fn(void *p1, void *p2, void *p3)
{
	ARG_UNUSED(p1);
	ARG_UNUSED(p2);
	ARG_UNUSED(p3);

	int err;

	err = dmic_trigger(dmic_dev, DMIC_TRIGGER_START);
	if (err < 0) {
		/* No watchdog is armed yet, so this leaves the device cloud-alive
		 * but deaf -- same as the pre-thread behavior. It has never been
		 * seen in the field; the watchdog deliberately only arms once
		 * capture has started so boot cannot trip it.
		 */
		LOG_ERR("Failed to start DMIC (err %d)", err);
		return;
	}

	/* LED1 = audio sampling is live (mic is being read). Signals when to
	 * start speaking; LED0 still blinks on each wake-word detection.
	 * On battery-oriented builds this is a brief periodic pulse rather than
	 * a steady light: held on, the LED's few mA outweigh everything the
	 * connectivity duty cycle saves.
	 */
#if defined(CONFIG_APP_LED_HEARTBEAT)
	leds_heartbeat_start();
	LOG_INF("Audio sampling started (LED1 heartbeat every %d ms)",
		CONFIG_APP_LED_HEARTBEAT_INTERVAL_MS);
#else
	leds_on_led1();
	LOG_INF("Audio sampling started (LED1 on)");
#endif

	/* Arm the audio-loop liveness watchdog now that capture is running. Boot and
	 * the network wait are deliberately excluded so they cannot trip it; a wedge
	 * from here on (a silently deaf toilet) captures a coredump + reboots.
	 */
	audio_watchdog_start();

	while (true) {
		if (IS_ENABLED(CONFIG_APP_MODE_WW_GATED_KWS) ||
		    IS_ENABLED(CONFIG_APP_MODE_WW_ONLY)) {
			err = ww_loop();
			if (err) {
				break;
			}
		}

		if (IS_ENABLED(CONFIG_APP_MODE_WW_GATED_KWS)) {
			leds_on_led0();
		}

		if (IS_ENABLED(CONFIG_APP_MODE_WW_GATED_KWS) ||
		    IS_ENABLED(CONFIG_APP_MODE_KWS_ONLY)) {
			err = kws_loop();
			if (err) {
				break;
			}
		}

		if (IS_ENABLED(CONFIG_APP_MODE_WW_GATED_KWS)) {
			leds_off_led0();
		}
	}

	/* Exiting stops the watchdog feeds, so a persistent pipeline failure
	 * ends in a coredump + reboot rather than a silently deaf device.
	 */
	LOG_ERR("Audio loop exited (err %d); audio watchdog will recover", err);
}

K_THREAD_DEFINE(audio, CONFIG_APP_AUDIO_THREAD_STACK_SIZE, audio_thread_fn, NULL, NULL, NULL,
		CONFIG_APP_AUDIO_THREAD_PRIORITY, 0, SYS_FOREVER_MS);

int main(void)
{
	int err;

	/* Boot marker: prints the running firmware version. Use this to confirm a
	 * FOTA swap actually took effect (the new image reports the new version).
	 */
	LOG_INF("Smart Toilet firmware v%s starting", APP_VERSION_EXTENDED_STRING);

	err = dmic_init();
	if (err) {
		return err;
	}

	err = leds_init();
	if (err) {
		return err;
	}

	err = control_output_init();
	if (err) {
		return err;
	}

	err = audio_snap_init();
	if (err) {
		return err;
	}

	err = actuator_init();
	if (err) {
		return err;
	}

	err = ww_init();
	if (err) {
		return err;
	}

	/* The keyword-spotting stage (and its ~26 KB model) is only needed in the
	 * KWS modes; in WW-only mode it is neither initialised nor linked
	 * (see CMakeLists.txt), saving the RAM the cloud/Memfault stack needs.
	 */
	if (!IS_ENABLED(CONFIG_APP_MODE_WW_ONLY)) {
		err = kws_init();
		if (err) {
			return err;
		}
	}

	LOG_INF("Initialization completed, check output on VCOM0");

	/* Prefer to let Wi-Fi come up first (so its TLS bring-up doesn't compete
	 * with the DMIC + edge-AI inference), but never gate the toilet's core
	 * voice function on the network: wait at most AUDIO_START_NET_WAIT_S, then
	 * start audio regardless. The cloud thread (cloud.c) keeps bringing up
	 * Wi-Fi/Memfault independently via conn_mgr, so they still connect later
	 * even if they are not ready yet here.
	 */
	LOG_INF("Waiting up to %d s for network before starting audio...",
		AUDIO_START_NET_WAIT_S);
	for (int i = 0; i < AUDIO_START_NET_WAIT_S && !cloud_is_connected(); i++) {
		k_sleep(K_SECONDS(1));
	}
	if (cloud_is_connected()) {
		LOG_INF("Network connected; starting audio capture");
	} else {
		LOG_WRN("No network after %d s; starting audio anyway "
			"(voice works offline; Wi-Fi/cloud will connect when available)",
			AUDIO_START_NET_WAIT_S);
	}

	/* Hand the pipeline to the dedicated audio thread (see audio_thread_fn
	 * above for the priority rationale). main's job ends here.
	 */
	k_thread_start(audio);

	return 0;
}

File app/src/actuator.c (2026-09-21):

/*
 * Copyright (c) 2026 Nordic Semiconductor ASA
 *
 * SPDX-License-Identifier: LicenseRef-Nordic-5-Clause
 */

#include <zephyr/drivers/gpio.h>
#include <zephyr/kernel.h>
#include <zephyr/logging/log.h>
#include <zephyr/sys/atomic.h>
#include <zephyr/sys/reboot.h>

#include <memfault/core/reboot_tracking.h>
#include <memfault/metrics/metrics.h>

#include "actuator.h"
#include "cloud.h"
#include "audio_telemetry.h"

LOG_MODULE_REGISTER(actuator);

/* How often the Hall sensor is sampled while the motor runs. */
#define MOTOR_POLL_MS	    1
/* Consecutive samples a new Hall level must hold to be accepted (debounce). */
#define HALL_DEBOUNCE_SAMPLES 3
/* Time after motor start during which the Hall is ignored. At rest the magnet
 * sits at the sensor; this blanking window lets the shaft move off home before
 * we start looking for the magnet's return, so start-up jitter cannot trigger
 * an immediate false stop.
 */
#define HALL_BLANKING_MS    250
/* Extra run time after the magnet is sensed. The shaft is still moving when
 * the magnet reaches the sensor, so a short overrun lets it rotate the rest
 * of the way to the proper resting spot.
 */
#define HALL_OVERRUN_MS	    50
/* Maximum motor run time. If the magnet is never sensed (jam, misaligned
 * magnet, faulty sensor) the motor is forced off so it cannot burn out.
 */
#define MOTOR_SAFETY_MS	    1500
/* Minimum time between flushes after the motor stops. */
#define FLUSH_LOCKOUT_MS    1000
/* Edges on the failsafe switch within this window are contact bounce. */
#define BUTTON_DEBOUNCE_MS  50

/* P1.06: HIGH = MOSFET on = motor runs (active high). */
static const struct gpio_dt_spec motor_gpio =
	GPIO_DT_SPEC_GET(DT_NODELABEL(flush_actuator), gpios);
/* P1.12: the sensor pulls the line low when the magnet is present (active
 * low, so a logical read of 1 means "magnet at sensor"). Moved off P1.07,
 * which the nRF7002 EB II claims as its coexistence GRANT pad.
 */
static const struct gpio_dt_spec hall_gpio =
	GPIO_DT_SPEC_GET(DT_NODELABEL(hall_sensor), gpios);
/* P1.08: failsafe flush switch to GND (active low, internal pull-up). */
static const struct gpio_dt_spec button_gpio =
	GPIO_DT_SPEC_GET(DT_NODELABEL(flush_button), gpios);
static struct gpio_callback button_cb;

static K_SEM_DEFINE(flush_sem, 0, 1);
static atomic_t motor_active;
/* k_uptime (ms) before which new flush requests are ignored. */
static int64_t lockout_until;

/* Debounced read of the Hall sensor: returns true when the magnet is present.
 * @p state holds the accepted level; @p cnt counts samples toward a change.
 */
static bool hall_present(bool *state, uint8_t *cnt)
{
	const bool raw = gpio_pin_get_dt(&hall_gpio) > 0;

	if (raw == *state) {
		*cnt = 0;
	} else if (++(*cnt) >= HALL_DEBOUNCE_SAMPLES) {
		*state = raw;
		*cnt = 0;
	}

	return *state;
}

/* Force the motor off. There is no safe way to leave a flush cycle with the
 * MOSFET possibly still driven, so a write failure gets one immediate retry
 * and then a reboot: actuator_init() reconfigures the pin GPIO_OUTPUT_INACTIVE
 * on every boot, which is the only way left to guarantee the motor de-energizes.
 */
static void motor_off_or_reboot(void)
{
	if (gpio_pin_set_dt(&motor_gpio, 0) == 0) {
		return;
	}

	if (gpio_pin_set_dt(&motor_gpio, 0) == 0) {
		return;
	}

	LOG_ERR("Flush: motor-off GPIO write failed twice; rebooting to force it safe");
	MEMFAULT_REBOOT_MARK_RESET_IMMINENT(kMfltRebootReason_HardFault);
	sys_reboot(SYS_REBOOT_WARM);
}

static void motor_run(void)
{
	uint8_t cnt = 0;
	/* Seed the debounced state with the level at start-up. */
	bool present = gpio_pin_get_dt(&hall_gpio) > 0;
	/* The magnet must be observed clear at least once before a later
	 * "present" reading is trusted as the real home-return stop condition.
	 * Without this, a magnet that never leaves home (jam, stuck sensor,
	 * shorted line) stops the motor at the first blanking-window check and
	 * gets reported as a completed flush.
	 */
	bool seen_clear = !present;

	if (gpio_pin_set_dt(&motor_gpio, 1) != 0) {
		LOG_ERR("Flush: motor-on GPIO write failed; aborting flush attempt");
		atomic_set(&motor_active, 0);
		return;
	}

	const int64_t start = k_uptime_get();
	bool jammed = false;

	LOG_INF("Flush: motor on (magnet %s at start)", present ? "present" : "clear");

	while (true) {
		const int64_t elapsed = k_uptime_get() - start;

		if (elapsed > MOTOR_SAFETY_MS) {
			LOG_WRN("Flush: safety timeout (%d ms), forcing motor off",
				MOTOR_SAFETY_MS);
			jammed = true;
			break;
		}

		present = hall_present(&present, &cnt);

		/* Track "has ever debounced clear" unconditionally, not just after
		 * blanking ends - a real cycle fast enough to leave and return home
		 * within the blanking window must still count as having cleared.
		 * Only the STOP decision itself is gated on the blanking window (to
		 * ignore start-up jitter as the shaft first leaves home).
		 */
		if (!present) {
			seen_clear = true;
		} else if (elapsed >= HALL_BLANKING_MS && seen_clear) {
			/* Genuine home return: the magnet left and came back. */
			LOG_INF("Flush: magnet sensed at +%lld ms, motor off after "
				"%d ms overrun", elapsed, HALL_OVERRUN_MS);
			k_msleep(HALL_OVERRUN_MS);
			break;
		}
		/* Else: magnet has been present since start and never cleared - the
		 * shaft hasn't moved. Keep running until the safety timeout; do not
		 * treat this as a stop condition.
		 */

		k_msleep(MOTOR_POLL_MS);
	}

	motor_off_or_reboot();
	lockout_until = k_uptime_get() + FLUSH_LOCKOUT_MS;
	atomic_set(&motor_active, 0);

	if (jammed) {
		/* Don't count a safety-timeout stop as a completed flush - the
		 * shaft may never have moved, so the toilet likely wasn't flushed.
		 */
		LOG_ERR("Flush: possible jam (magnet never left home); not reporting "
			"as a completed flush");
		memfault_metrics_heartbeat_add(MEMFAULT_METRICS_KEY(flush_jam_count), 1);
		return;
	}

	/* Report the completed flush to nRF Cloud (non-blocking). */
	cloud_report_flush();
}

static void motor_thread_fn(void *a, void *b, void *c)
{
	ARG_UNUSED(a);
	ARG_UNUSED(b);
	ARG_UNUSED(c);

	while (true) {
		k_sem_take(&flush_sem, K_FOREVER);
		motor_run();
	}
}

K_THREAD_DEFINE(motor_tid, 1024, motor_thread_fn, NULL, NULL, NULL,
		K_PRIO_PREEMPT(5), 0, 0);

static void button_pressed(const struct device *dev, struct gpio_callback *cb, uint32_t pins)
{
	ARG_UNUSED(dev);
	ARG_UNUSED(cb);
	ARG_UNUSED(pins);

	static int64_t last_edge;
	const int64_t now = k_uptime_get();

	if (now - last_edge < BUTTON_DEBOUNCE_MS) {
		return;
	}
	last_edge = now;

	LOG_INF("Failsafe switch pressed");
	cloud_report_button_press();
	audio_telemetry_button_press();
	actuator_flush();
}
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

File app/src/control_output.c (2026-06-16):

/*
 * Copyright (c) 2026 Nordic Semiconductor ASA
 *
 * SPDX-License-Identifier: LicenseRef-Nordic-5-Clause
 *
 * Control output: emits short status strings on the console (VCOM0 / uart30).
 *
 * NOTE: with the nRF7002 EB II shield, the console is rerouted to uart30 -- the
 * same UART this used to own via the async API. Two owners on one UART break
 * console output, so we now print through the console (printk) instead. Status
 * messages share VCOM0 with the Zephyr log.
 */

#include <stddef.h>

#include <zephyr/kernel.h>
#include <zephyr/sys/printk.h>

#include "control_output.h"

static const char *const messages[] = {
	[CONTROL_MESSAGE_WAITING_WW] = "Waiting for wakeword\r\n",
	[CONTROL_MESSAGE_WW_DETECTED] = "Wakeword detected\r\n",

	[CONTROL_MESSAGE_WAITING_KW] = "Waiting for keywords\r\n",
	[CONTROL_MESSAGE_KW_SPOTTED] = "Keyword spotted: %s\r\n",
	[CONTROL_MESSAGE_TIMEOUT_KWS] = "Keyword spotting window timeout\r\n",
};

BUILD_ASSERT(CONTROL_MESSAGE_COUNT == ARRAY_SIZE(messages),
	     "Mismatch between control_message_type and messages size");

int control_output_init(void)
{
	return 0;
}

void print_control_output(const struct control_message message)
{
	if (message.type >= CONTROL_MESSAGE_COUNT) {
		return;
	}

	if (message.type == CONTROL_MESSAGE_KW_SPOTTED) {
		printk(messages[message.type], message.name);
	} else {
		printk("%s", messages[message.type]);
	}
}

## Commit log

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2026-06-11 Tune wake word for fast repeats; fix 3 s refractory dead zone
    Telemetry showed inference only completes every third 10 ms DMIC block,
    so WW_REFRACTORY_FRAMES=100 was ~3 s of post-detection deafness (not the
    intended ~1 s), silently swallowing repeated utterances. Set it to 33
    (~1 s), clear the vote history when the refractory expires so stale
    tail votes cannot contaminate the next utterance, and report stats
    every 33 frames so they really are per-second.
    Tuning, verified live on the DK: flush lockout 3 s -> 1 s, vote
    threshold 10 -> 7, probability bar 0.80 -> 0.60, PDM gain +12 -> +16 dB.
    +20 dB rails close/loud speech at 0 dBFS, where the model outputs a
    flat prob 0.00 - saturation is wors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
    [actuator.c]
2026-06-11 Add audio front-end: 120 Hz high-pass filter and software AGC
    New CONFIG_APP_AUDIO_PROC module cleans each DMIC block in place before
    detection. A 2nd-order Butterworth high-pass at 120 Hz strips rumble and
    handling noise below the speech band. The AGC tracks utterance peaks and
    pulls them toward CONFIG_APP_AGC_TARGET_DBFS (-20 dBFS) within a +/-12 dB
    software range - rising slowly (~300 ms) to avoid warping a word
    mid-utterance, dropping fast (~50 ms) to step away from saturation, and
    holding below -38 dBFS so silence does not pump the noise floor. A
    per-second "agc:" telemetry line accompanies the audio stats, which now
    report post-processing levels (what the model actually receives).
    Ver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
    [main.c]
2026-06-12 Add audio snapshot recording over the control UART
    Sending the trigger byte 'S' on the control UART (VCOM0) records
    CONFIG_APP_AUDIO_SNAP_SECONDS (default 10 s, 32 KB RAM per second) of
    the processed mic audio - exactly what the wake-word model receives -
    then dumps it back over the same UART as an "AUDIO_SNAP <bytes>" header
    followed by raw 16-bit little-endian PCM. The control UART gains RX
    support and a raw binary mode that holds queued control messages back
    during a dump so text cannot corrupt the stream. Detection keeps
    running throughout.
    The new "snap" subcommand in tools/uart_monitor.py triggers a snapshot
    and saves it as a mono 16 kHz WAV.
    Listening to snapshots settled the far-fi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
    [audio_snap.c, control_output.c, main.c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]
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2026-06-13 Add 3D-printable enclosure (OpenSCAD + STL) (#1)
    * Add a failsafe flush switch on P1.08
    A manual switch between P1.08 and GND triggers a flush directly,
    bypassing the voice pipeline. The line uses the internal pull-up
    (active low) with an edge interrupt; edges within 50 ms are treated
    as contact bounce, and the existing motor-active and lockout guards
    in actuator_flush() apply unchanged.
    * Run the motor 35 ms past Hall detection
    The shaft is still moving when the magnet reaches the sensor, so
    stopping immediately left it short of the proper resting spot. Keep
    the motor on for a short overrun (HALL_OVERRUN_MS) after the magnet
    is sens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
    [enclosure.scad, enclosure.stl, magic_symbols.scad]
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2026-06-17 Fix cloud_tid bus fault: separate newlib heap from common malloc arena
    The merged app bus-faulted in cloud_tid during nRF Cloud CoAP JWT
    generation (heap chunk_field, wild pointer, ASCII data in registers).
    Root cause: a dual-heap collision. The Wi-Fi supplicant force-selects
    CONFIG_COMMON_LIBC_MALLOC (hostap Kconfig), whose arena with the default
    ARENA_SIZE=-1 spans _end..RAM-end. The Edge AI library forces newlib,
    whose mprec float-formatting (Balloc/_Bfree, exercised by cJSON/JWT on
    the cloud path) uses its own _sbrk heap -- also based at _end. The two
    heaps overlapped and corrupted each other's chunk metadata. The standalone
    nrf_cloud sample avoids this only because it uses picolibc (no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
    [main.c]
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2026-06-17 Wire flush events + count to nRF Cloud over CoAP
    cloud.c now reports each completed flush as a FLUSH device message
    (nrf_cloud_coap_sensor_send) and pushes a flushCount value to the device
    shadow, with the lifetime count persisted in NVS (settings) and restored
    on boot. The connected loop services flush events as they happen and polls
    the shadow delta every 15s for a remote {"flush":true} command, which
    triggers actuator_flush() and reconciles the shadow.
    actuator.c calls cloud_report_flush() (non-blocking: bumps a counter and
    wakes the cloud thread) when a flush completes.
    Verified on hardware: "abracadabra" -> flush -> "Reported flush #N to
    nRF Cloud"; count persists across reboot.
    Co-A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
    [actuator.c, cloud.c]
2026-06-18 Add Memfault: coredumps + metrics forwarded via nRF Cloud CoAP
    Enable the Memfault SDK (CONFIG_MEMFAULT) for on-device coredump capture
    (RAM-backed), reboot-reason tracking, metrics, and a GNU build ID for
    symbolication. Device serial = HW ID (MEMFAULT_NCS_DEVICE_ID_HW_ID), so it
    matches the nRF Cloud device ID. No device-side project key (NCS >= v3.0
    allows empty for forwarding devices).
    Transport: the built-in MEMFAULT_USE_NRF_CLOUD_COAP path depends on
    MODEM_JWT (cellular) and can't be enabled on this Wi-Fi build, so cloud.c
    forwards Memfault chunks itself -- it drains the packetizer and POSTs to
    nRF Cloud's "chunks" CoAP resource via nrf_cloud_coap_post(), reusing the
    existing APP_JWT-a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
    [cloud.c]
2026-06-18 Reduce RAM 94%->76% (and flash 63%->45%)
    Optimizations, all verified on hardware (connects, DTLS handshake OK,
    Memfault uploads 2.01, wake-word listening):
    - Drop the unused KWS stage in APP_MODE_WW_ONLY: kws_init() is gated and the
    KWS sources/model are not linked (CMakeLists target_sources_ifndef). Frees
    the ~26 KB model state (and ~360 KB flash).
    - cloud_tid stack 16384 -> 6144 (the DTLS+JWT work needs far less; 16K was
    over-provisioned while chasing the heap-collision bug).
    - mbedTLS heap 80000 -> 49152 (ample for one CoAP DTLS session).
    - COMMON_LIBC_MALLOC_ARENA_SIZE 65536 -> 40960 (cJSON/sockets fit; the freed
    RAM also goes to newlib's _sbrk heap).
    Also keep CONFIG_RESET_ON_F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
    [cloud.c, main.c]
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2026-06-19 Bump Hall overrun to 150 ms; fix README cloud build command
    - HALL_OVERRUN_MS 100 -> 150 so the motor runs a touch longer past the
    magnet, landing the mechanism more reliably in the home position.
    - README build command: EXTRA_CONF_FILE was "app/cloud.conf", which CMake
    resolves relative to the app source dir (app/app/cloud.conf) and fails;
    corrected to "cloud.conf". Dropped the edge-impulse-sdk-zephyr extra
    module (not present / not required for this build).
    [actuator.c]
2026-06-19 Shorten Hall overrun back to 100 ms
    With the Hall sensor wiring fixed, flushes now complete reliably at
    ~415 ms, so the extra 50 ms of overrun added while debugging is no longer
    needed. Revert to the original 100 ms.
    [actuator.c]
2026-06-19 Shorten Hall overrun to 50 ms
    Flushes complete reliably and stop close to home with a shorter overrun;
    50 ms is enough to carry the magnet just past the sensor.
    [actuator.c]
2026-06-19 Fix stale Hall pin comment: P1.07 -> P1.12
    The devicetree moved the Hall sensor to P1.12 (P1.07 is the nRF7002 EB II
    coexistence GRANT pad), but the comment still said P1.07. Match the overlay.
    [actuator.c]
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2026-06-19 Spike: nRF Cloud CoAP FOTA download client (MCUboot, external secondary)
    Builds the FOTA path end to end (compiles + links; not yet flashed/tested):
    - Bootloader/partitioning: switch to Partition Manager (required - the
    fota_download/dfu_target libs include pm_config.h unconditionally) and use
    SB_CONFIG_PM_EXTERNAL_FLASH_MCUBOOT_SECONDARY to place mcuboot_secondary in
    the onboard MX25R64. Dropped the manual DTS partition surgery PM replaces.
    - Client (cloud.conf): NRF_CLOUD_FOTA_POLL + NRF_CLOUD_COAP_DOWNLOADS (image
    pulled over the existing CoAP link, no extra HTTPS cert) + FOTA_DOWNLOAD +
    DFU_TARGET_MCUBOOT + IMG_MANAGER; advertise app-FOTA in the shadow; CoAP
    extended options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
    [cloud.c]
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2026-06-22 Start audio after a bounded wait for network, not unconditionally (v1.6.0)
    Audio capture was gated on the first network connection (while
    (!cloud_is_connected())), so if the unit booted during a Wi-Fi outage it blocked
    forever and never started the mic — the toilet couldn't hear the wake word until
    Wi-Fi returned. Voice is the core function and must not depend on the cloud.
    main.c: wait at most AUDIO_START_NET_WAIT_S (30 s) for network, then start audio
    regardless. Normal boots behave as before (Wi-Fi first); an outage no longer
    leaves the toilet deaf. Wi-Fi/Memfault still connect later — the cloud thread
    brings them up independently via conn_mgr (persistent connect), unaffected by
    this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
    [main.c]
2026-06-23 Don't let a transient DMIC read error kill the audio loop (v1.7.0)
    Intermittent "stops responding to the wake word until reboot" bug. ww_loop()
    (and kws_loop()) returned on any dmic_read() error, and main() returns on a
    non-zero ww_loop() result — so a single transient DMIC read failure exited the
    audio thread permanently. The mic was never read again; the device stayed online
    (cloud thread alive, telemetry flowing) but deaf until reboot, which is why it
    looked healthy and the failure was intermittent.
    dmic_read() returns -EAGAIN (-11) when no block arrives within DMIC_READ_TIMEOUT
    (100 ms) — a momentary stall, e.g. CPU contention during Wi-Fi reconnection.
    Observed in earlier captures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
    [main.c]
2026-06-23 Harden ww/kws_process errors so audio loop survives them too (v1.8.0)
    Completes the audio-loop robustness work begun in v1.7.0 (DMIC reads). An
    edge-AI feed/inference error from ww_process()/kws_process() (e.g. -EPERM, not
    the normal -EBUSY) was still treated as fatal: ww_loop()/kws_loop() returned,
    main() returns on that, and the audio thread exited permanently — the same
    "deaf until reboot" failure mode, just a rarer trigger.
    Now: on a non-EBUSY process error, log a warning, re-initialise the model state
    (ww_reset()/kws_reset(), which re-inits the Axon persistent vars), and continue.
    The dmic_read() at the loop top paces retries. The audio loop no longer exits on
    any transient — DMIC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
    [main.c]
2026-07-02 Fix Wi-Fi MAC collision and add Toilet #2 onboarding creds
    - cloud.conf: switch to CONFIG_WIFI_RANDOM_MAC_ADDRESS (fixed MAC collides across identical units)
    - nrfcloud_creds: onboarding cert/CSR/pub-key + result CSV for device 779FC2ACB9E4A24E (Toilet #2); private key excluded via .gitignore
    - PROFILING.md: battery profiling runbook
    [onboard_result.csv]
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2026-07-02 Reboot if the cloud thread stalls silently (v1.8.3)
    The Memfault HTTP client connects with a plain blocking zsock_connect()
    on a SOL_TLS socket — the TLS handshake has no timeout, so a network
    hiccup mid-handshake can park cloud_tid forever. Heartbeat uploads and
    FOTA checks share that thread, so one hung connect silently kills all
    cloud contact while Wi-Fi, audio, and the motor keep running (observed
    on both units: Toilet #1 dark since its last check-in, Toilet #2's
    diag-build session).
    Add a stall monitor: the thread stamps a progress timestamp every loop
    iteration; a 60 s timer reboots (warm) if no progress for 15 min while
    the network is up, first marking a SoftwareWatchdog reboot rea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
    [cloud.c]
2026-07-02 Add connectivity uptime and TCP/IP stats to Memfault diagnostics (v1.8.4)
    - cloud.c: feed memfault_metrics_connectivity_connected_state_change() on
    Started/Connected/ConnectionLost so connection_uptime_percent actually
    gets data (the metric API was compiled in but never fed). Verified this
    is not the cause of the earlier silent-stall issue (A/B tested against
    the v1.8.3 stall-watchdog fix).
    - cloud.conf: enable CONFIG_NET_STATISTICS(+_USER_API) so the already-on
    CONFIG_MEMFAULT_METRICS_TCP_IP has real data (retransmits, bytes sent/
    received) to report each heartbeat.
    - Bump to 1.8.4 and fix CONFIG_MCUBOOT_IMGTOOL_SIGN_VERSION, which had
    drifted stale at 1.8.0 through the 1.8.1/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
    [cloud.c]
2026-07-02 Fix code-review findings: jam detection, GPIO/error handling, dead-code gate (v1.8.5)
    actuator.c:
    - Distinguish a genuine flush from a jammed/stuck-at-home magnet. Previously
    `present` was seeded from the Hall reading at motor start, and any later
    "present" reading (even one that never went false) was accepted as the stop
    condition - a stuck/jammed magnet stopped the motor after ~300ms and got
    reported as a completed flush. Now a `seen_clear` flag must go true (magnet
    actually read absent at least once) before a later "present" is trusted;
    otherwise the motor runs to the existing safety timeout and is logged as a
    jam via a new flush_jam_count Memfault metric, not reported as a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
    [actuator.c, cloud.c]
2026-07-06 Add audio-loop liveness watchdog with coredump capture (v1.8.6)
    audio_watchdog.c/.h: the wake-word audio loop feeds a progress timestamp each
    iteration; a 15 s k_timer fires MEMFAULT_TASK_WATCHDOG() (coredump + reboot) if
    the loop makes no progress for 60 s. Catches a truly wedged main thread (blocked
    in dmic_read / edge-AI inference) that the continue-on-error fixes don't cover --
    the suspected cause of Toilet #2 going silently deaf while the cloud thread died
    and the GPIO-ISR flush button kept working.
    cloud.c: upgrade the v1.8.3 cloud stall watchdog from a reason-only warm reboot
    to MEMFAULT_SOFTWARE_WATCHDOG() so cloud-thread stalls also capture a coredump
    (backtrace of where cloud_tid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
    [cloud.c, main.c]
2026-07-06 Add Wi-Fi disconnection watchdog to recover a stuck link (v1.8.7)
    cloud.c: the stall monitor now guards the DISCONNECTED state too. It arms on
    the first successful L4 connect; if Wi-Fi then stays down for DISCONNECT_REBOOT_S
    (10 min), it warm-reboots to force a clean nRF70/supplicant bring-up. conn_mgr
    persistence (already on) retries association, but a wedged supplicant/driver only
    clears on a reset. Armed only after a first connect, so a unit simply out of
    range never reboot-loops -- worst case one reboot per outage, then it parks and
    the offline voice/flush path keeps working.
    Fixes the observed failure where Toilet #2, in a weak-signal spot, dropped off
    Wi-Fi and never recovered (no reb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
    [cloud.c]
2026-07-06 Add upload-success watchdog: reboot+coredump if Memfault unreachable (v1.8.8)
    The cloud-stall watchdog trusts the cloud thread's self-progress and the
    disconnection watchdog trusts conn_mgr's `connected` flag; a wedge in the seam
    between them -- L4 nominally connected while nothing actually reaches Memfault
    -- trips neither, which is the Toilet #2 soft-hang (dead 6 h, no watchdog, no
    fault). Add a third watchdog keyed on the real goal: stamp every confirmed
    Memfault round-trip (data POST or FOTA-check success); if none for 20 min after
    having uploaded at least once this boot, capture a coredump (MEMFAULT_SOFTWARE_
    WATCHDOG -> the wedged thread's backtrace) and reboot. Gated on ever_uploaded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
    [cloud.c]
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2026-07-07 Keepalive + reconnect-not-reboot for silent Wi-Fi drops (v1.8.10)
    Toilet #2 kept crashing on 1.8.9. Root cause (from telemetry): a silent half-open
    link. Legacy Wi-Fi power save (kept ON for the low-power roadmap) + the Nest mesh
    deauth/steer the dozing client without the nRF70 noticing -- wifi_disconnect_count
    stayed 0 through an 11 h run while the link was actually dead, so every socket op
    (getaddrinfo, TLS) failed until the watchdog rebooted. TWT -- which would avoid
    this -- is unavailable: the Nest AP reports no TWT on 5 GHz and the nRF7002 has no
    6 GHz radio.
    Two fixes, power save left ON:
    - cloud.conf: CONFIG_NRF_WIFI_FEAT_KEEPALIVE (30 s) -- periodic frame keeps an
    idle client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
    [cloud.c]
2026-07-08 Fix reconnect stack overflow + faster half-open detection (v1.8.11)
    v1.8.10's reconnect-not-reboot work ran on the 4 KB system workqueue, but
    conn_mgr disconnect/connect's Wi-Fi/supplicant cascade overflowed it -> HardFault
    (2 Asserts on #2 within a day). Telemetry also showed the silent Wi-Fi drop hits
    BOTH units (Nest mesh steering/dropping them: #2 often, #1 ~every 14 h) -- the
    watchdogs recover them but firmware cannot prevent the mesh drop, and moving the
    units / changing the network are not options.
    So make recovery clean and fast:
    - cloud.conf: SYSTEM_WORKQUEUE_STACK_SIZE 4096 -> 8192, so the reconnect
    completes instead of faulting.
    - cloud.c: FOTA/connectivity check 120 -> 6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
    [cloud.c]
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2026-07-09 Report flushes as per-interval events, not a running total (v1.9.1)
    flush_count was published every heartbeat with heartbeat_set_unsigned() set
    to the lifetime NVS total, so the Memfault timeseries showed an ever-growing
    number instead of activity. Switch to heartbeat_add(flush_count, 1) per flush
    (same pattern as ww_detections): Memfault resets it each heartbeat, so the
    metric reads flushes-per-interval and sums to flushes-per-day. The lifetime
    total stays in NVS for the device's own record but is no longer reported.
    [cloud.c]
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2026-07-10 Add button_press_count heartbeat metric (v2.0.4)
    Differentiates how flushes are triggered: the failsafe button vs. the wake
    word. Per-interval unsigned counter alongside flush_count, so voice flushes
    ~= flush_count - button_press_count on the dashboard.
    The button GPIO ISR cannot call Memfault metric APIs (they lock a mutex), so
    cloud_report_button_press() stages the press ISR-safely (atomic_inc +
    k_sem_give, mirroring cloud_report_flush) and the cloud thread drains it into
    the metric in record_flushes(). Hooked into the debounced button_pressed() ISR
    so one press = one count.
    First release delivered over the air on the repaired FOTA path (8 KB
    downloader stack, v2.0.3).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
    [actuator.c, cloud.c]
2026-07-11 Feed audio watchdog on pipeline progress + reconnect visibility (v2.0.5)
    Overnight, #2's DMIC/inference pipeline wedged for ~45 min after a Wi-Fi
    reconnect (ww_inferences 19880 -> 0 while heartbeats kept flowing): the audio
    watchdog was fed at the TOP of the loop, so a persistently failing dmic_read()
    spun through the error path petting the watchdog forever. Move the feeds to
    pipeline-progress points (mic block read AND accepted by the model, or a full
    inference) in both ww_loop and kws_loop; the DMIC/inference error paths
    deliberately do not feed, so a persistent failure now trips the 60 s audio
    watchdog -> coredump (with the wedge visible) -> reboot -> recovered voice.
    Cloud-stall follow-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
    [cloud.c, main.c]
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2026-07-11 Self-heal a wedged DMIC by restarting PDM capture in-place (v2.0.7)
    Root cause found via the first logs-in-coredump capture (issue 1805218207,
    2026-07-11 18:54): a Wi-Fi scan ("wpa_supp: Timed out waiting for scan
    results") stalls the CPU long enough to overrun the PDM ring; the nrfx PDM
    driver halts capture and dmic_read() returns -EAGAIN forever ("DMIC read error
    -11" wall-to-wall in the attached log). Reads alone never recover a halted
    driver -- capture must be retriggered.
    Add dmic_restart() (STOP -> START + PDM gain re-apply) and call it from both
    audio loops after DMIC_ERRS_BEFORE_RESTART=10 consecutive read failures (~1 s).
    Turns the scan-induced mic wedge from a 60 s audio-watchdog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
    [main.c]
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2026-07-13 Fix the three fleet reset causes: FOTA WDT, DMIC slab, Wi-Fi heap (v2.0.11)
    Investigation of the 2026-07-10..13 reset wave found three distinct causes:
    1. Every OTA apply was reported as a bogus "Hardware Watchdog" reboot: the
    nRF WDT keeps counting across the soft reset into MCUboot, whose swap
    against the external MX25R64 SPI-NOR outlasts the 120 s budget and fires
    mid-swap (synchronized on both devices at every version boundary).
    Raise the hardware backstop to 10 min; the 60 s software watchdogs
    remain the fast, coredump-producing detectors.
    2. The DMIC self-heal added in v2.0.7 never actually recovered: each PDM
    wedge strands up to 2 slab blocks inside the driver, so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
    [cloud.c]
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2026-07-15 Keep audio alive through Wi-Fi recovery + fix daily CDR starvation (v2.0.13)
    Three fixes, all prompted by Toilet #2's ~daily Wi-Fi disconnect-recovery
    reboot that starved its edge-AI observability CDR:
    1. Daily CDR (prj.conf): AUTO_COLLECT interval 24h -> 12h. The collect timer
    and the in-RAM histogram both reset on every reboot, so a unit that reboots
    before 24h uptime (Toilet #2, ~22-23h) never completes a window and ships no
    CDR (last one 2026-07-12). 12h lands within a sub-24h uptime; Memfault still
    retains <=1 CDR/device/day.
    2. Wi-Fi disconnect recovery without a reboot (cloud.c): the genuine-disconnect
    path now recovers the link on the cloud thread, escalating with ti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
    [cloud.c, main.c]
2026-07-15 Roll back audio-first boot: it deafened the whole fleet (v2.0.14)
    v2.0.13's audio-first boot (start the DMIC immediately instead of waiting up
    to 30 s for Wi-Fi) raced PDM start against the concurrent nRF70/Wi-Fi bring-up
    and corrupted DMIC capture: both toilets came up with a railed mic (peak 0
    dBFS, noise floor -13, clip count ~2.5-4.5k) and inference collapsed to ~565
    per 10-min window (normal ~20k), i.e. deaf. Neither audio watchdog caught it
    (saturated but not the exact railed+>50%-clipping shape, and the slow loop
    still fed liveness), so it sat silently deaf with healthy heartbeats.
    Revert main.c to the proven v2.0.12 boot order: wait up to 30 s for Wi-Fi to
    finish its CPU/RAM-heavy b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
    [main.c]
2026-07-17 Move audio pipeline to a priority-0 thread above wpa_supplicant (v2.0.15)
    The wake-word loop ran on the priority-6 main thread while wpa_supplicant
    runs at 0, so Wi-Fi scan/reconnect bursts could stall dmic_read() past the
    ~40 ms the 4-block PDM ring tolerates and halt capture (the recurring
    "DMIC read error -11" walls). Audio now runs on a dedicated priority-0
    thread and the supplicant drops to 3 (equal-priority threads never preempt
    each other in Zephyr, so 0-vs-0 would keep the stall window open). The
    nRF70 IRQ (-15 coop) and BH (0) workqueues stay at/above audio, leaving
    Wi-Fi interrupt handling untouched. Watchdog semantics unchanged: armed
    after capture starts, fed on pipeline progress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
    [main.c]
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2026-07-25 Phase 1: duty-cycled connectivity (v2.1.0, low-power branch)
    Wake on a period, connect, drain accumulated Memfault data, run one FOTA
    check, then take the interface fully down (radio off) until the next
    period. Simple by design: the window takes however long it takes; the only
    bail-out is Wi-Fi not associating within 5 min (retry next period).
    Between windows there is no association at all, so the half-open-link,
    silent-drop, and link-flap heap-pressure failure classes cannot occur
    offline. The recovery ladder and its watchdogs arm only while a window is
    open; the one always-armed backstop is the upload watchdog stretched to
    two full periods. Flush/button events are recorded (metrics + NVS)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
    [cloud.c]
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
